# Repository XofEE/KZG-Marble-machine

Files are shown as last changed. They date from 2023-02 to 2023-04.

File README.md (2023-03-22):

# KZG-Marble-machine by Xofee

Resources and documentation related to the KZG Marble machine.

## Summary

This machine was built by [Xofee](https://twitter.com/Xofee3) in order to generate randomness to participate in the KZG ceremony.
It uses chaos theory to capture entropy. The KZG Marble Machine is a physical device that generates random numbers using the natural randomness of marble movement.

The KZG Ceremony is a public ritual aimed at providing a cryptographic foundation for Ethereum scaling efforts like proto-danksharding.

If you want more information about the KZG Ceremony, you can find it on the dedicated [GitHub Pages](https://github.com/ethereum/kzg-ceremony).
To see the machine in operation, go to this [video](https://www.youtube.com/watch?v=zKrcUxOeBF4).

## Presentation

The machine is a marble circuit. There are 13 obstacles retracing in chronological order the history of Ethereum:

- White paper
- First blocks
- Attacks
- NFT madness
- Maze of the DEFI
- The Burn
- Mining area
- The Merge
- Flow of staking
- Layers 2
- Data Blob
- Vision of the future
- Rocket lift

A complete description of each obstacle can be found in the file [Full-presentation.md](/Full-presentation.md)

## How it works

Thanks to a set of sensors, it measures the time between marbles, and it is also sensitive to its external environment.

Each time a ball completes the course, it is detected by a sensor. This causes a measurement on all the other sensors and also some light animations.
These values are aggregated and then output in one random number via USB.

Some obstacles are mechanical or motorized with servomotors. The latter also serves as a sensor to add entropy.
The course is embellished with animated LEDs to make it more entertaining.
The public present in front of the machine also participates in the entropy thanks to the microphone, light sensor and the ultrasonic sensor which measures the distance of the public from the machine.

To contribute to the KZG ceremony, the machine will directly generate a new long string of random values which will be used as a secret.
**This secret will not be recorded and will therefore be lost after participation.**

This special contribution for the KZG ceremony will take place after mid-March.

The KZG Marble Machine uses a physical process to generate randomness, which means it is not subject to the same potential biases and patterns that can be present in pseudorandom number generators. This can provide a higher level of security in applications where true randomness is essential.

The KZG Marble Machine is a physical device, which means it is more resistant to tampering than a software-based random number generator. If an attacker wants to manipulate the output of the KZG Marble Machine, they would need to physically access the device and interfere with the marbles, which can be more difficult than manipulating software.

## Random facts about the machine and its construction

- It took a total of more than 8 days of 3D printing to make all the pieces.
- A marble is detected by the sensor on average every 2.5s
- It takes about 25s for a ball to complete the full course.
- There are 42 marbles in the circuit in total, 30 of which are in the elevator.
- The course measures more than 4m in total.
- The longest obstacle is the DEFI maze which alone represents a quarter of the course.

## More info

You can find more info about the machine in the file [Full-presentation.md](/Full-presentation.md).

A [data set](/Data) of more than 16,000 values generated by the machine (CSV file available in raw, hexadecimal or binary) is available.
You can use them as random values in your projects or analyze them to check that the machine is not biased.

If you have any questions, don't hesitate to contact me on twitter at [Xofee](https://twitter.com/Xofee3).

*Randomly Xofee*

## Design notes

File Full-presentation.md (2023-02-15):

# Full presentation of The KZG Marble Machine by Xofee

## Summary 

This presentation aims to supplement the information found in the [Readme file](/README.md).

If you want more information about the KZG Ceremony, you can find it on the dedicated [GitHub Pages](https://github.com/ethereum/kzg-ceremony).

To see the machine in operation, go to this [video](https://www.youtube.com/watch?v=zKrcUxOeBF4).

## Obstacles 

We will deconstruct each obstacle of the KZG Marble Machine to understand its functioning.



The best place to start is with the title: ETHEREUM. We'll take a look at some of its major milestones.



In 2014, Vitalik published the Ethereum White Paper 📝, which marked the beginning of the project. This obstacle is powered by the logo rotating randomly 🔄, deflecting the marbles.



In 2015, 🏁 the first blocks of Ethereum were mine and worked smoothly until...



In 2016, there was a setback with the hack of The DAO and the Shanghai attack. Here we see a funnel that sucks all the marbles 🌪️.



In 2017, the NFT craze is depicted with a CryptoKitty (#634995) congesting the marble flow with its paws. 🐾



We delve into the complexities of decentralized finance with the 2020 DEFI Summer.



We find the 🔥 Burn mechanism of the EIP1559 with a switch that diverts some of the marbles. This update was implemented during the London fork in August 2021.



Next, we come to the moment of the merge symbolized by a panda 🐼. Upstream, we have the miners' pickaxes ⛏️ representing the Proof of Work era.



In September 2022, we move to proof of stake with the marbles flowing between the ETH staked 🪙.



We then reach the layer 2, which operates in parallel ⛓️ with Ethereum to improve scalability.



We arrive at a blob that absorbs data to make more room for the layer 2s. The KZG ceremony 🕯️ with the EIP 4844 will enable the deployment of this new data type.



The end of the course features a sensor measuring the final interval between two marbles to generate entropy 🎲. Then we discover a vision of a future built on Ethereum 🏙️.



Finally, we come to a rocket 🚀 (familiar to some in the community) which uses an elevator to raise the marbles to the top of the course. ⏫

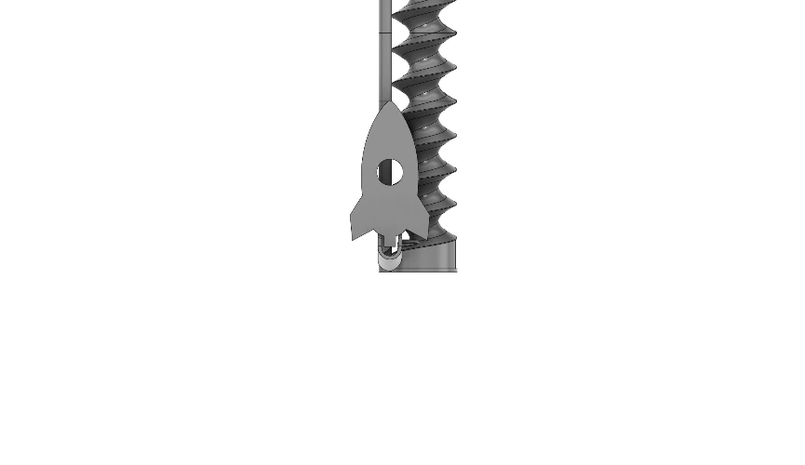
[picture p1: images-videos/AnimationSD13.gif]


## Source of entropy

The machine draws its entropy mainly from the measurement of the time between the passage of two marbles.
Indeed, during its course, each marble will follow a slightly different path which will make it encounter greatly different obstacles.
In addition, the obstacles move to add even more randomness.

The accumulation of these parameters as well as their chaotic characteristic means that the machine can be considered capable of generating pseudo random values.

Secondary entropy sources such as noise, temperature are also captured by sensors to be added as well.

### Primary

| Description  | Sensor | Range |
| - | - | - |
|Time interval between two balls| LJ12A3-4-Z/BX|~2 500 000 μs - ~12 000 000 µs|

### Secondary

| Description  | Sensor | Range |
| - | - | - |
| Sound | Adafruit MAX4466 | 0 - 1023 |
| Brightness | Iduino 1485310 | 0 - 1023 |
| Distance | Ultrasonic 28015 REV C | 0mm - 500mm |
| Electrostatic noise | Antenna length 40 cm | 0 - 1023 |
| Electrostatic noise | Antenna length 40 cm | 0 - 1023 |
| Electrostatic noise | 6 x ADC | 6 x 0 - 1023 |
| Temperature | 4 x Robotis Dynamixel MX-28AR | 4 x 0 - 255 |
| Load | 4 x Robotis Dynamixel MX-28AR | 4 x 0 - 2047 |
| Position | 4 x Robotis Dynamixel MX-28AR | 4 x 0 - 4095|

## Output

The machine aggregates all the parameters of its sensors.

It can then output this value directly* or convert it to hexadecimal or binary simply performing a modulo 16 or 2 respectively.

The order of magnitude of the sum of the outputs of all the sensors being greater than 10<sub>5</sub>, a modulo 16 can loop enough times for this value to be unpredictable.

In other words, a modulo 10 will come down to looking at the last value of a sensor outputting a 6-digit result. However, the latter is mainly influenced by the noise and not by the measured variable.

**be careful with this raw value the distribution is not homogeneous because there are more balls that finish in 2.5s than in 10s for example.*

## Control of obstacles

### Motorized obstacle

4 obstacles are controlled by servomotors:

- White paper
- NFT madness
- Mining area
- Rocket lift

These servos change speed and position randomly according to the last generated random value.
This change happens every time a marble completes the circuit or every 5s (whichever comes first).

### Mechanical obstacle

The burn is a special obstacle since it is a switch that separates half of the marbles. The burnt balls are sent on a faster path towards the end of the course.

## List of materials:

If you want to build this machine yourself, you will find below a non-exhaustive list of the necessary materials:

- White and gray PLA 3D printed parts
- Back board 45x66cm
- 4 x Robotis Dynamixel MX-28AR
- 1 x OpenCM 9.04 board
- 1 x OpenCM EXP 485 power board
- 1 x 12v 3A powersupply
- 1 x LJ12A3-4-Z/BX inductive proximity sensor
- 1 x Mic Adafruit MAX4466
- 1 x Brightness sensor Iduino 1485310
- 1 x Ultrasonic sensor 28015 REV C
- 2 x Strip of Neopixels LED

[Files](/3D%20files) and [code](/program) are available in opensource on this github.

If you have any questions, don't hesitate to contact me on twitter at [Xofee](https://twitter.com/Xofee3).

*Randomly Xofee*

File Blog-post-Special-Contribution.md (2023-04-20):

# The KZG Marble Machine: My special Contribution to Ethereum’s KZG Ceremony
## Subtitle:

*A closer look at the elaborate contraption that uses marbles to generate random numbers for the Ethereum KZG Ceremony.*

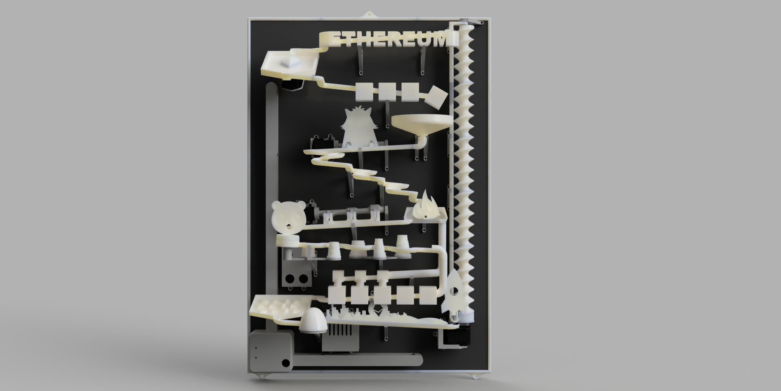
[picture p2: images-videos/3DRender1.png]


*The KZG Marble Machine*

## Introduction:
Cryptography is a fascinating world that thrives on creativity and innovation. In this extended blog post, I’m excited to share details about my one-of-a-kind contribution to the Ethereum KZG Ceremony using the KZG Marble Machine, an elaborate contraption designed to provide a unique source of randomness for the proceedings.

## Background:
The KZG Ceremony is a decentralized alternative to a trusted setup, which outputs public parameters for a polynomial commitment scheme. The ceremony relies on contributions from multiple participants, guaranteeing integrity as long as at least one participant acts honestly in generating their contribution and destroying the secret.

To reinforce the ceremony’s security, the Ethereum Foundation called for special contributions, including unique sources of randomness.

That’s where my KZG Marble Machine comes into play!

## The KZG Marble Machine:
The KZG Marble Machine is an intricate, custom-built contraption that uses marbles to generate random numbers. The machine features 13 obstacles, each symbolizing a milestone in Ethereum’s history. As marbles move through the machine, they interact with these obstacles and various components, creating unpredictable patterns. The result is a truly unique and random sequence of numbers that I used for my special contribution to the KZG Ceremony.

To see the machine in operation, go to this [video](https://www.youtube.com/watch?v=zKrcUxOeBF4).

## Entropy Sources:
Multiple entropy sources influence the machine’s sensors, ensuring an even higher degree of randomness. These sources include the initial position of the marbles, friction between components, air resistance, and vibrations in the machine’s structure.

Additionally, the KZG Marble Machine is equipped with ultrasonic sensors, microphones, and antennas, which incorporate environmental factors as supplementary sources of entropy. This feature allows the machine to generate even more unpredictable random numbers.



*Breakdown of the full KZG Marble Machine*

## The Process:
The KZG Marble Machine sent 420 random hexadecimal values (i.e. 1680 values in binary) through the serial port of an air-gapped PC via a USB cable. This air-gapped PC performed the necessary computations to generate my contribution to the KZG Ceremony. Once the calculations were completed, I transferred the resulting file to a USB stick and then to a separate computer, which sent my contribution to the sequencer.

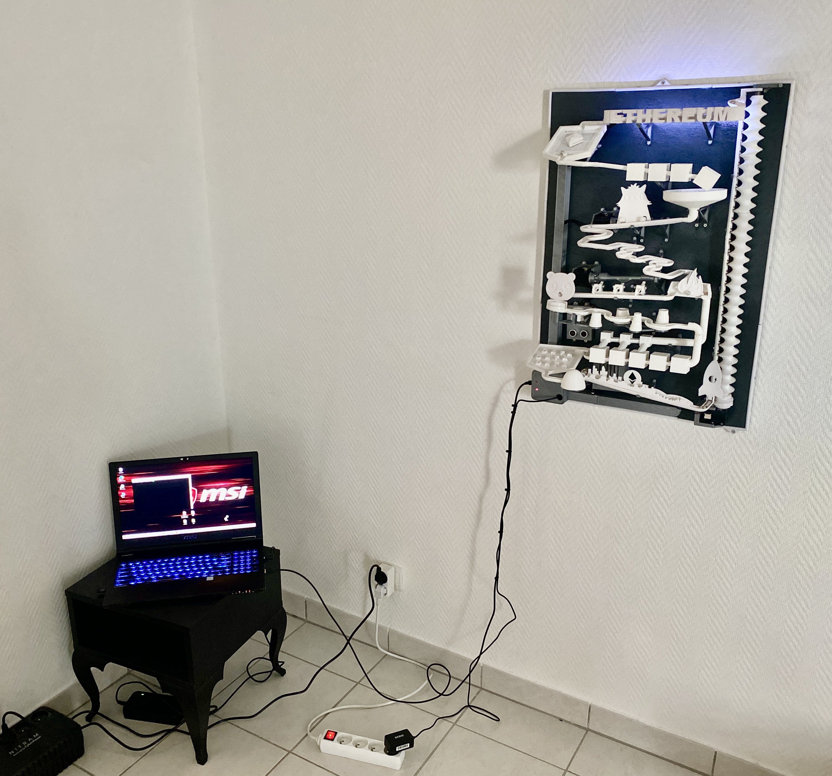
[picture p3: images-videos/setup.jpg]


*Setup beforethe contribution*

Importantly, the 420 random hexadecimal values were never recorded nor fully seen by me. After transferring the file, both the air-gapped PC and the USB stick were completely formatted to ensure no trace of the random values or my contribution remained.

## Documentation:
For more information on the KZG Marble Machine and the process, please visit the [GitHub Pages](https://github.com/ethereum/kzg-ceremony).
The machine is fully opensourced. All 3D files, programs and component list are available on Github.

## Proof of Contribution:
As proof of my contribution, here is a screenshot of the sequencer showing my Ethereum address ( xofee.eth : 0xFF141bFc450c57Ad84eBaFbD09ffa94A268a7aaE ) and contribution number (#83329) .

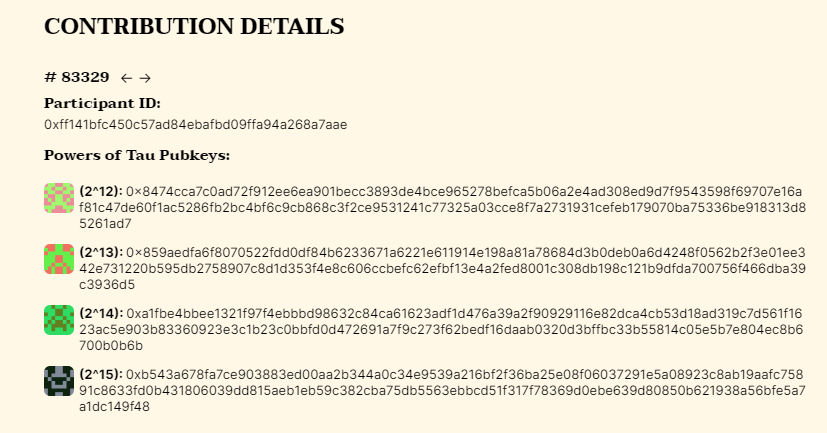
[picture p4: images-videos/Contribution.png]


*#83329 Contribution details*

[My twitter post](https://twitter.com/Xofee3/status/1644033756066467840?s=20)

## Conclusion:
The KZG Marble Machine is a unique and innovative contribution to the KZG Ceremony. Its ability to generate random numbers using marbles and various sources of entropy makes it a valuable addition to the security of the ceremony. The machine’s intricate design and the attention to detail that went into its creation are a testament to the creativity and innovation that thrives in the world of cryptography. The fact that the machine is open-sourced further enhances its value as a contribution to the Ethereum community, and its documentation provides valuable insights into the process. Finally, we should not forget to thank all the people involved in making this possible, from the organizers of the KZG Ceremony to those who provided support and inspiration along the way.

Overall, the KZG Marble Machine is a fascinating example of how creativity and innovation can contribute to the security of decentralized systems.

*Randomly Xofee*

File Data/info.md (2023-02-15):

# Data set info

This folder contains a data set with 16500 random values generated by the machine.
These measurements was made in more than 12 hours of operation of the machine.
You can use them as random values in your owns projects or analyze them to check that the machine is not biased.
The files are in CSV format.

The raw.csv file contains the aggregated values of all sensors each time a marble passes in front of the sensor.     
**be careful with this raw value the distribution is not homogeneous because there are more balls that finish in 2.5s than in 10s for example.*

The hex.csv and bin.csv files give the same values in Hexadecimal and in binary. 
**These are the pseudo-random data generated by the machine.**
They are obtained by respectively performing a modulo 16 and 2 on the raw data.

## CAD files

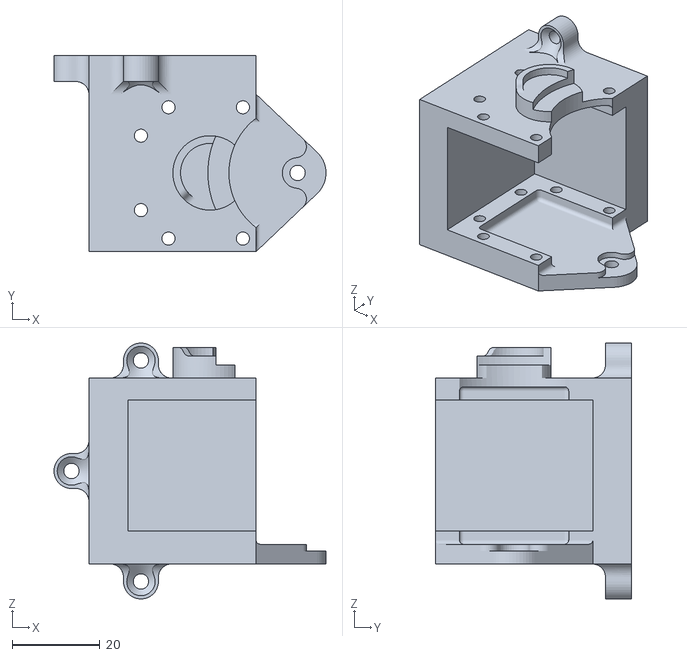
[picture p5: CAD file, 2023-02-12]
3D files/STL/00-Assembly v20_00-Assembly v20_13-Servo v1_1_Corps1.stl
62.2 x 44.9 x 58.5

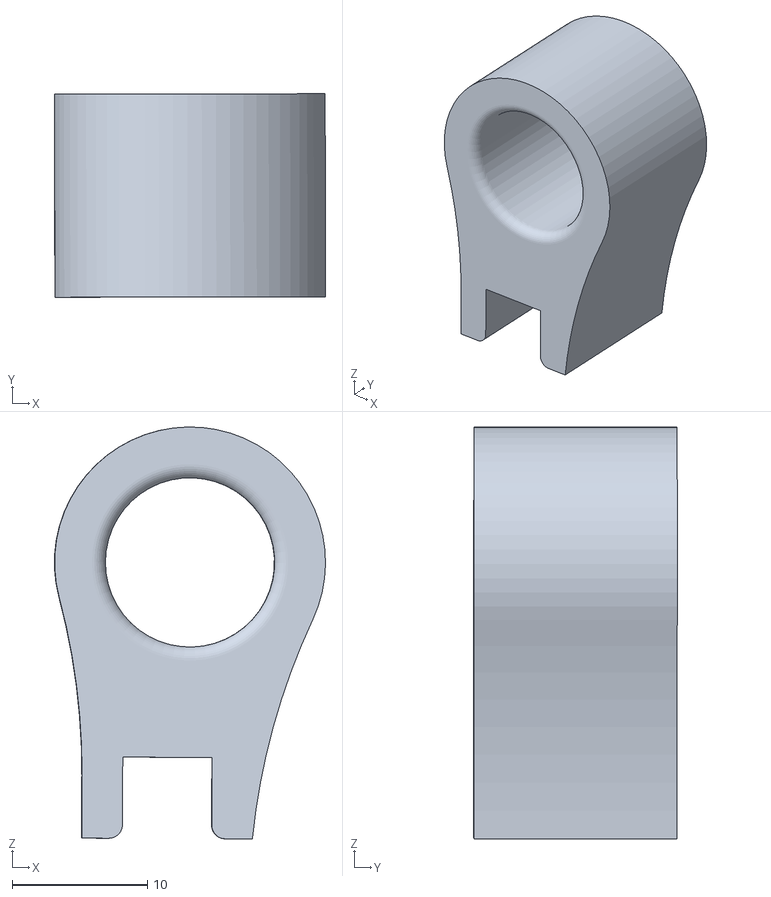
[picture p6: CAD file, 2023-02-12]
3D files/STL/00-Assembly v20_00-Assembly v20_12-support Sensor v1_1_Corps1.stl
20.0 x 15.0 x 30.4

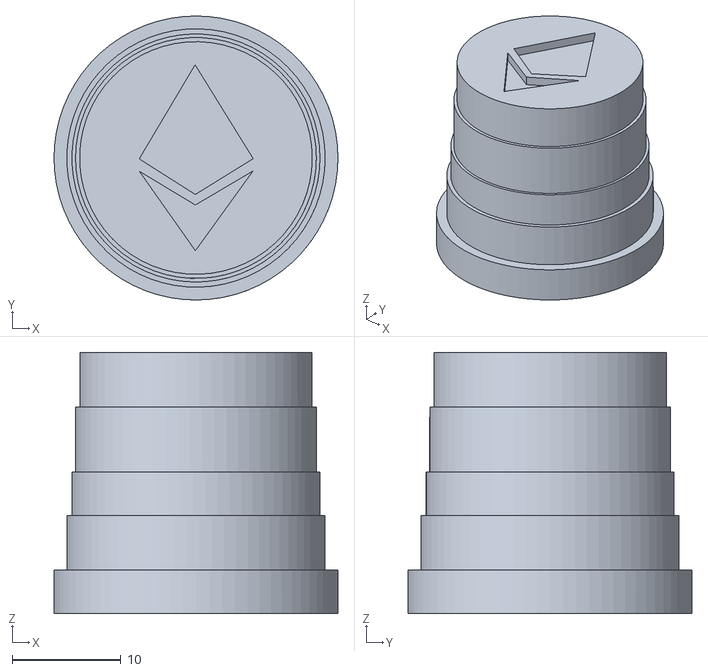
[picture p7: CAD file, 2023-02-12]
3D files/STL/00-Assembly v20_00-Assembly v20_09-Staking v6_1_Corps5.stl
26.1 x 26.1 x 24.0

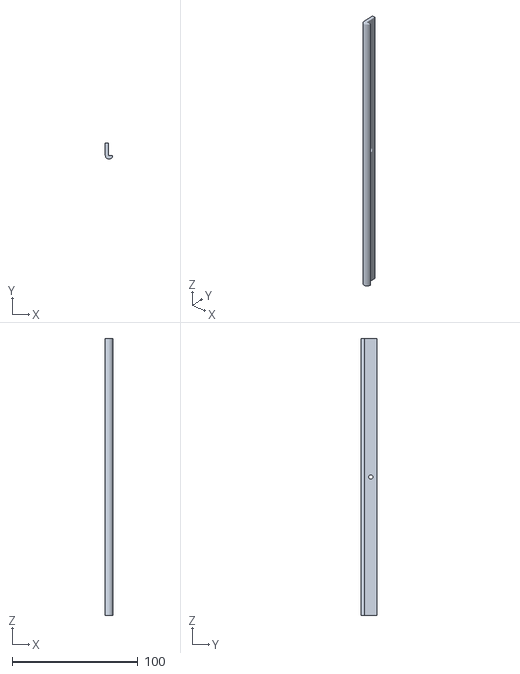
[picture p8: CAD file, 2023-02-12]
3D files/STL/00-Assembly v20_00-Assembly v20_Edge (CL).stl
6.00 x 13.0 x 220.0

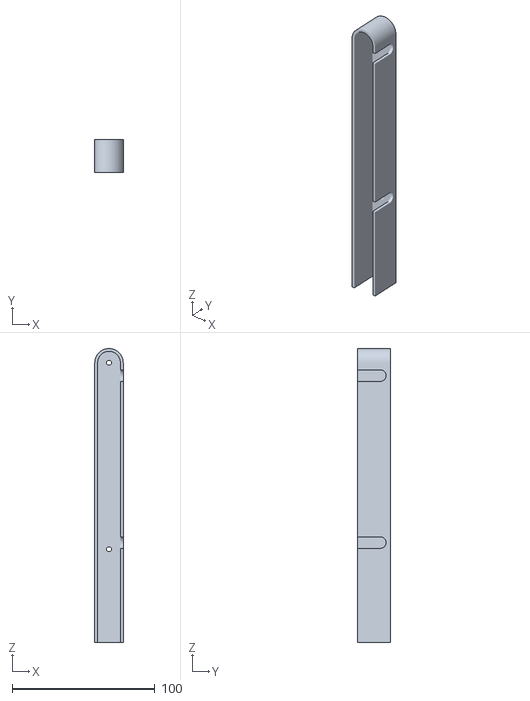
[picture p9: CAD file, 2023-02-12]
3D files/STL/00-Assembly v20_00-Assembly v20_Cable v10_1_A.stl
20.0 x 23.0 x 206.0

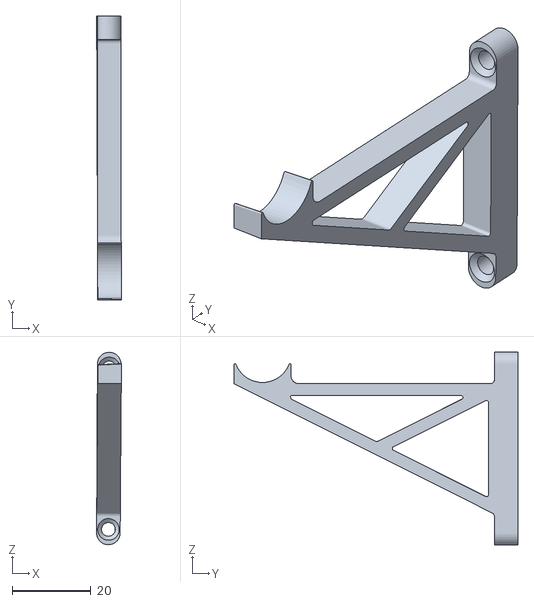
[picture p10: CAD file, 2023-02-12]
3D files/STL/00-Assembly v20_00-Assembly v20_10-support6mm v1_1_Corps1.stl
6.32 x 72.3 x 49.0

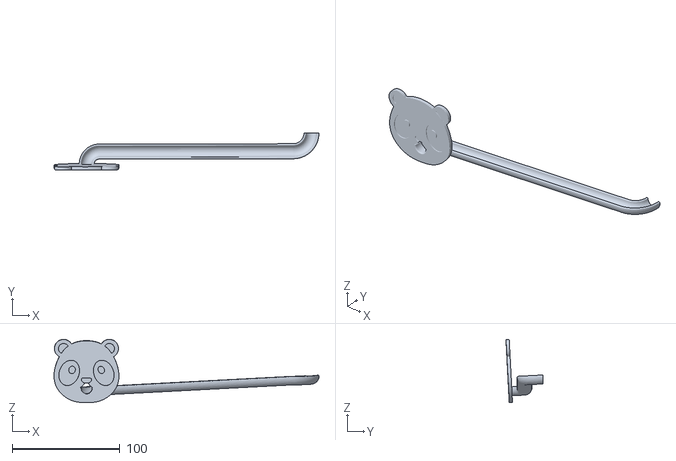
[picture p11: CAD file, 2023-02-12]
3D files/STL/00-Assembly v20_00-Assembly v20_08-Miner v10_1_Corps1.stl
246.1 x 34.5 x 58.9

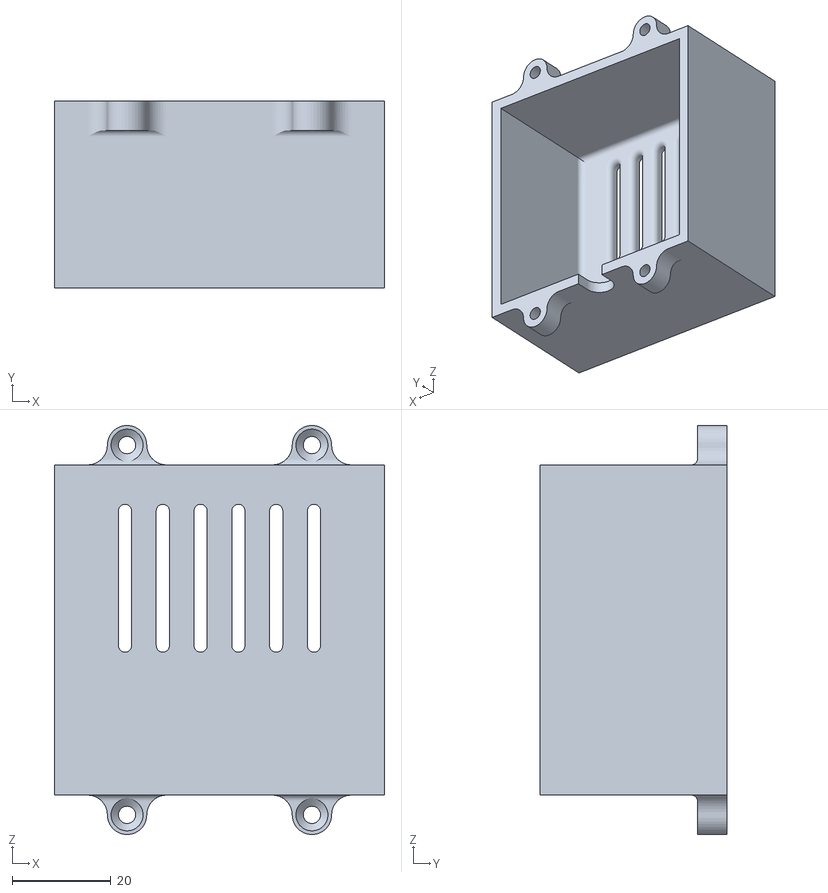
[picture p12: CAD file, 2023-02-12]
3D files/STL/00-Assembly v20_00-Assembly v20_LedBox v1_1_Corps1.stl
67.0 x 38.0 x 83.0

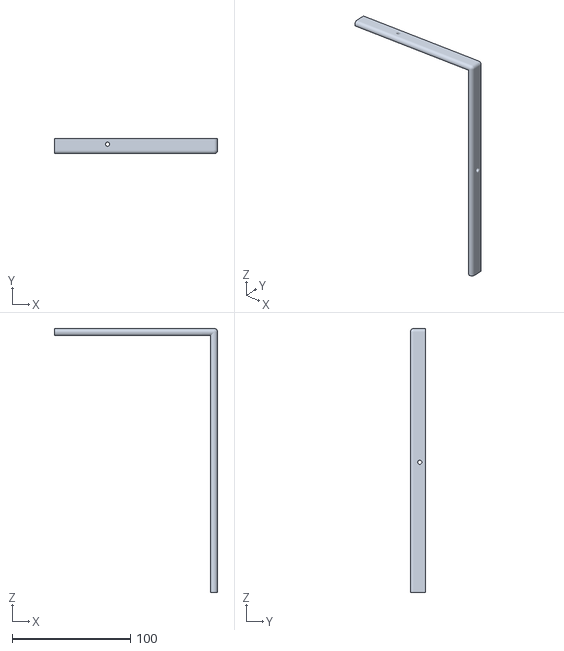
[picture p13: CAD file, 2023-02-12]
3D files/STL/00-Assembly v20_00-Assembly v20_Edge (UR).stl
138.0 x 13.0 x 223.0

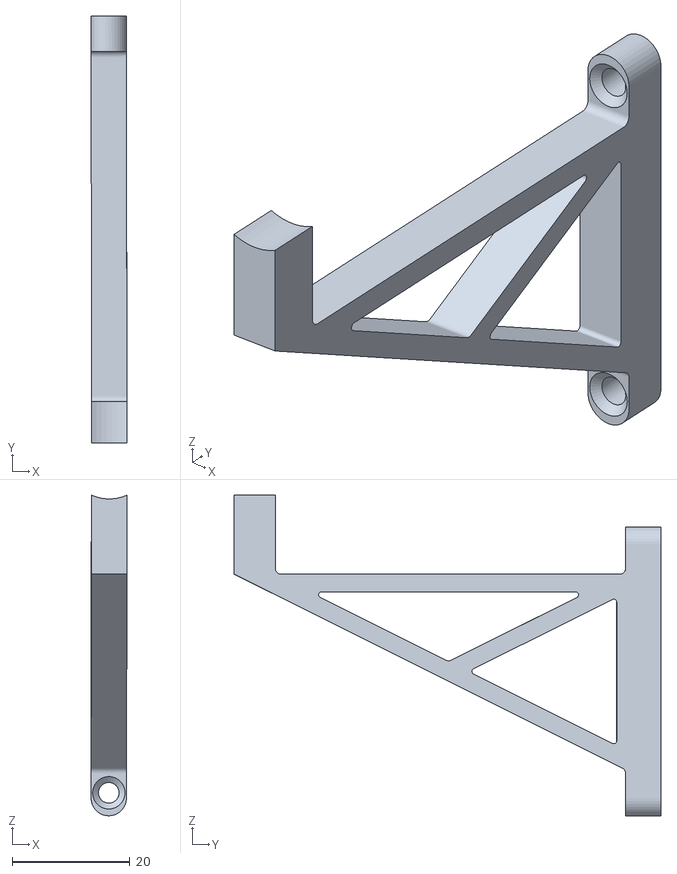
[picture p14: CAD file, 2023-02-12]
3D files/STL/00-Assembly v20_00-Assembly v20_07-support6mm v1_1_Corps1.stl
6.12 x 72.4 x 54.4

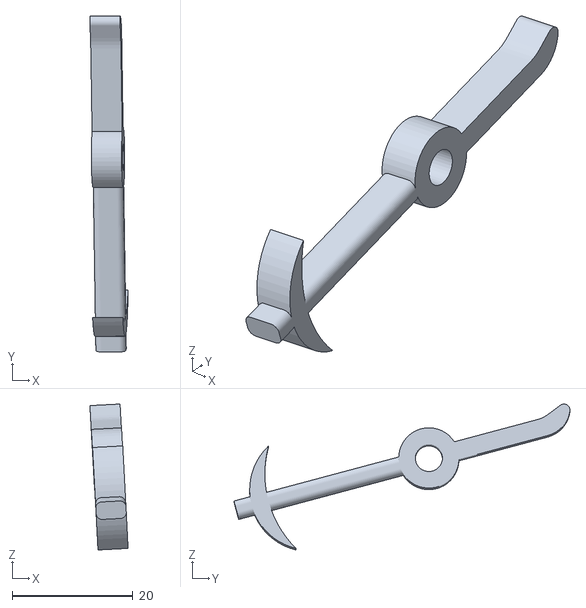
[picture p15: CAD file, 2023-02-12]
3D files/STL/00-Assembly v20_00-Assembly v20_08-Miner v10_1_Pioche(Symétrie miroir) (1)_1_Corps1.stl
6.32 x 55.6 x 24.2

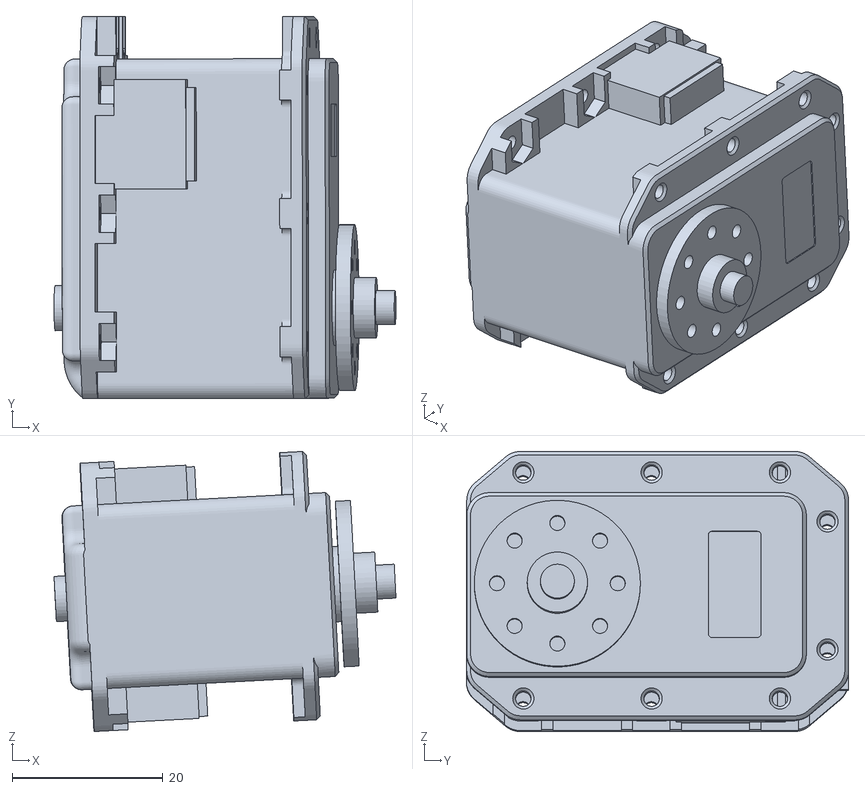
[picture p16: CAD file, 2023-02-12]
3D files/STL/00-Assembly v20_00-Assembly v20_08-Servo v1_1_MX-28AT_AR v2_1_Corps1.stl
45.3 x 50.6 x 37.1

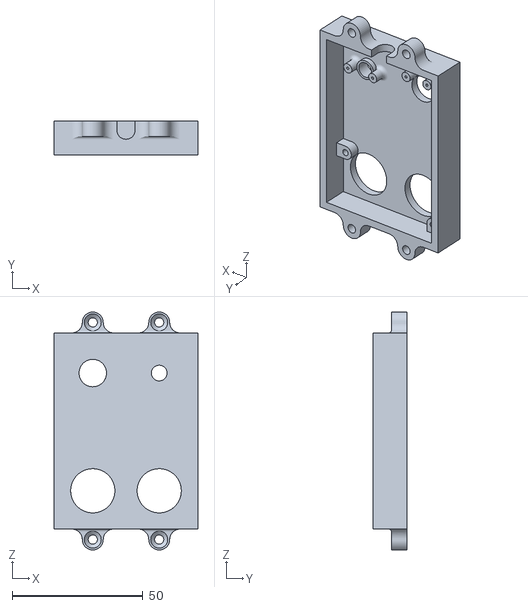
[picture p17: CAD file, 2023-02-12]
3D files/STL/00-Assembly v20_00-Assembly v20_SensorsBox v3_1_Corps2.stl
55.0 x 13.0 x 91.0

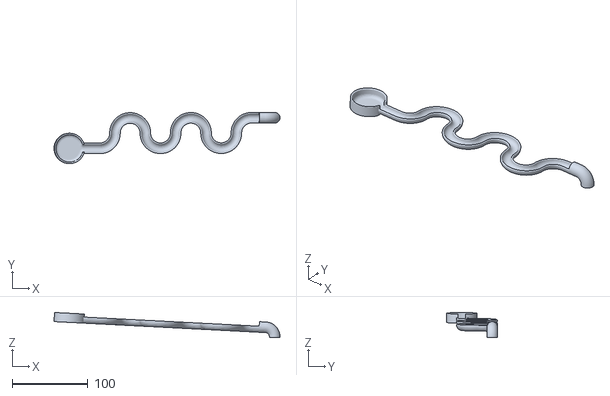
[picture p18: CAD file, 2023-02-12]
3D files/STL/00-Assembly v20_00-Assembly v20_09-Staking v6_1_Corps1.stl
297.4 x 67.4 x 33.0

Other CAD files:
3D files/STL/00-Assembly v20_00-Assembly v20_Cable v10_1_Corps20.stl
3D files/STL/00-Assembly v20_00-Assembly v20_Edge (BR).stl
3D files/STL/00-Assembly v20_00-Assembly v20_09-support6mm v1_1_Corps1.stl
3D files/STL/00-Assembly v20_00-Assembly v20_09-Staking v6_1_Corps2.stl
3D files/STL/00-Assembly v20_00-Assembly v20_01-Ethereum v7_1_Corps15.stl
3D files/STL/00-Assembly v20_00-Assembly v20_01-support6mm v2_1_Corps1.stl
3D files/STL/00-Assembly v20_00-Assembly v20_01-support6mm v2_2_Corps1.stl
3D files/STL/00-Assembly v20_00-Assembly v20_02-Whitepaper v7_1_02-Servo v6_1_Corps1.stl
3D files/STL/00-Assembly v20_00-Assembly v20_02-Whitepaper v7_1_Corps1.stl
3D files/STL/00-Assembly v20_00-Assembly v20_02-Whitepaper v7_1_Corps13.stl
3D files/STL/00-Assembly v20_00-Assembly v20_02-Whitepaper v7_1_Corps4.stl
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

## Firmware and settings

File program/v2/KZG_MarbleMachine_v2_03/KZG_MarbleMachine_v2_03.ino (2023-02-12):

#include <Adafruit_NeoPixel.h> //library for LED

/* Display Output mode */
#define HEXA 0
#define BINA 0
#define TIME 0
#define VALU 1

/* Parameters */
#define TCHANGE 5000 //max time between change of speed for Dynamixel  
#define BRI 50 //LED Brightness
#define TCUT 500 //min time between 2 values to skip rebounce or double marbles
#define TLED 300//time for led animation


/* ID Servo defines Robotis Dynamixel MX-28AR */
#define ELE 1 //Elevator
#define MIN 2 //Miner
#define CAT 3 //Crypto Kitty
#define EWP 4 //Ethereum White Paper

/* Pin defines */
#define SEN 18 //Inductive Proximity Sensorb LJ12A3-4-Z/BX

#define SOU 3 //digital pin for neopixe
#define LUM 1 //digital pin for neopixel
#define ULT 19 //digital pin for neopixel
#define ANT1 8 //digital pin for neopixe
#define ANT2 9 //digital pin for neopixel

#define LEDH 21 //digital pin for neopixe
#define LEDB 20 //digital pin for neopixel

/* Dynamixel Control table defines */
#define CW_Angle_Limit 6
#define CCW_Angle_Limit 8
#define GOAL_SPEED 32
#define PRESENT_POSITION 36
#define PRESENT_LOAD 40
#define PRESENT_TEMPERATURE 43
#define MOVING 46

 /* Serial device defines for dxl bus */
Dynamixel Dxl(3);

Adafruit_NeoPixel pxB = Adafruit_NeoPixel(32, LEDB, NEO_GRB + NEO_KHZ800);
Adafruit_NeoPixel pxH = Adafruit_NeoPixel(32, LEDH, NEO_GRB + NEO_KHZ800);


unsigned long t_marble =0; //timer between marble
unsigned long val =0; //random value output
unsigned long t_change =0; //random value output
unsigned long t_led =0; //random value output
int pos[5];
int load[5];
int temp[5];

byte lineH=0;
byte lineB[200];

float xH=0;

/*Setup*/
void setup() {
  //Pin configuration
  pinMode(SEN, INPUT_PULLDOWN);//sensor pin
  pinMode(ULT, INPUT_PULLDOWN);//ultrason pin
  
  for(int i =0;i<10;i++){//config analog pin to add as a source of noise 
    pinMode(i, INPUT_ANALOG);
  }

  // Dynamixel 2.0 Protocol -> 0: 9600, 1: 57600, 2: 115200, 3: 1Mbps 
  Dxl.begin(1);
  
  
  //Wheelmode
  Dxl.writeWord(ELE, CW_Angle_Limit, 0);
  Dxl.writeWord(ELE, CCW_Angle_Limit, 0); 
  
  Dxl.writeWord(MIN, CW_Angle_Limit, 0);  
  Dxl.writeWord(MIN, CCW_Angle_Limit, 0);
  
  Dxl.writeWord(CAT, CW_Angle_Limit, 0); 
  Dxl.writeWord(CAT, CCW_Angle_Limit, 0); 
  
  //JointMode
  Dxl.writeWord(ELE, CW_Angle_Limit, 0);
  Dxl.writeWord(ELE, CCW_Angle_Limit, 0); 
 
  
  //Start wheel mode servo
  Dxl.writeWord(ELE, GOAL_SPEED, 300 | 0x400); //reverse
  Dxl.writeWord(MIN, GOAL_SPEED, 100);
  Dxl.writeWord(CAT, GOAL_SPEED, 100);
  
  //Start servo
  Dxl.setPosition(EWP,2048,100);
  
  //Start time
  t_marble=micros(); //save time for restart counter
  t_change=micros(); //save time for restart counter
  
  read_dynamixel();//update value from dynamixels sensors and analogpin
  
  for(int i =0;i<150;i++){//init array with zeros 
    lineB[i]=0;
  }

  //Start led
  pxH.begin();
  pxH.setBrightness(BRI);
  
  pxB.begin();
  pxB.setBrightness(BRI);
  
  update_led();
  
}

/*Loop*/
void loop() {
  
  if((digitalRead(SEN)==LOW) && (abs(micros()-t_marble) > TCUT*1000)){// if there is a new marble more than TCUT ms after the last
  
    digitalWrite(BOARD_LED_PIN, LOW);//LED on board ON
    update_value();//update value with sensors from all dynamixel and analog pin
    ultrasound(); //update value with ultrasound sensor
    
    
    if (HEXA) SerialUSB.print(val%16,HEX);
    else if (BINA) SerialUSB.print(val%2);
    else if (TIME) SerialUSB.println(micros()-t_marble);
    else if (VALU) SerialUSB.println(val);
    
    t_marble=micros(); //save time for restart counter
    t_change= t_change-TCHANGE*1000;//force update servo
    
    sinB();//add pulse lEDB 
    
    while (digitalRead(SEN)==LOW) delay(50);//wait for stuck marble or no Power
  }
  else {
    digitalWrite(BOARD_LED_PIN, HIGH);//LED on board OFF
  }
  
  //change speed of servo if marble detected or too long
  if (abs(micros()-t_change) > TCHANGE*1000){
    t_change=micros(); //save time for restart counter
    
    update_value();//update value with sensors from all dynamixel
    
    //change speed of dynamixel
    Dxl.writeWord(ELE, GOAL_SPEED, 200+val%101 | 0x400); //101 arbitrary value
    Dxl.writeWord(MIN, GOAL_SPEED, 100+val%43); //43 arbitrary value
    Dxl.writeWord(CAT, GOAL_SPEED, 100+val%193);//193 arbitrary value
    
    Dxl.setPosition(EWP,1365+val%1021,50+val%101);//101 arbitrary value
    }
    
    if (micros()%TLED*1000==0){//sinus on LEDH
    xH=xH+0.0031415;
    if (xH>3.1415) xH=0.0;
    
    lineH=20+sin(xH)*50;
    }
    
    
    if(micros()%900==0){//update LED
      move_line();
      update_led();
    }  
    

}

/*Fonctions*/

int read_dynamixel(void){//read sensors from all dynamixel
  for (int i=0;i<4;i++){
    pos[i+1] =Dxl.readWord(i+1, PRESENT_POSITION);
    load[i+1]=Dxl.readWord(i+1, PRESENT_LOAD);
    temp[i+1]=Dxl.readByte(i+1, PRESENT_TEMPERATURE);
  } 
  
  return 0;
}

int update_value(void){//update value with sensors from all dynamixel
  val = micros()-t_marble; //calculation of the time interval between two marbles
    
    read_dynamixel();//read value from dynamixels sensors    
    for (int i=0;i<4;i++){//adding values from Dynamixel Servos sensors
    val = val + pos[i+1];
    val = val + load[i+1];
    val = val + temp[i+1];
  } 
  
  for(int i =0;i<10;i++){
    val = val + analogRead(i);//add value from floating analog pin, antenna, light sensor and mic
  }
  
  return 0;
}

int ultrasound(void){
    // establish variables for duration of the ping, and the distance result
  // in centimeters:
  float duration, mm;

  // The PING))) is triggered by a HIGH pulse of 2 or more microseconds.
  // Give a short LOW pulse beforehand to ensure a clean HIGH pulse:
  pinMode(ULT, OUTPUT);
  digitalWrite(ULT, LOW);
  delayMicroseconds(2);
  digitalWrite(ULT, HIGH);
  delayMicroseconds(5);
  digitalWrite(ULT, LOW);

  // The same pin is used to read the signal from the PING))): a HIGH pulse
  // whose duration is the time (in microseconds) from the sending of the ping
  // to the reception of its echo off of an object.
  pinMode(ULT, INPUT);
  duration = rdpulseIn(ULT, HIGH,50);

  // convert the time into a distance in mm
  mm = duration/58.2;
  
  val = val+mm;//
  
  return 0;
}

unsigned long rdpulseIn(int pin, int value, int timeout) { // the following comments assume that we're passing HIGH as value. timeout is in milliseconds

    unsigned long now = micros();
    while(digitalRead(pin) == value) { // wait if pin is already HIGH when the function is called, but timeout if it never goes LOW
        if (micros() - now > (timeout*1000)) {
            return 0;
        }
    }

    now = micros(); // could delete this line if you want only one timeout period from the start until the actual pulse width timing starts
    while (digitalRead(pin) != value) { // pin is LOW, wait for it to go HIGH befor we start timing, but timeout if it never goes HIGH within the timeout period
        if (micros() - now > (timeout*1000)) { 
            return 0;
        }
    }

    now = micros();
    while (digitalRead(pin) == value) { // start timing the HIGH pulse width, but time out if over timeout milliseconds
        if (micros() - now > (timeout*1000)) {
            return 0;
        }
    }
    return micros() - now;
}

int move_line(void){//move array right for B
  for(int i =0;i<149;i++){
    lineB[149-i]=lineB[148-i];
  }
 return 0; 
}

int sinB(void){//add sinus to the start of LEDB array
  float x =0.0;
  for(int i =0;i<20;i++){
    lineB[i]=sin(x)*255;
    x=x+0.157;
  }
 return 0; 
}

int update_led(void){//update LED
  for(int i =0;i<13;i++){
    pxH.setPixelColor(i,lineH,lineH,lineH); 
  }
  pxH.show();
  for(int i =0;i<11;i++){
    pxB.setPixelColor(i,lineB[i*10+59],lineB[i*10+59],lineB[i*10+59]);
  }
  pxB.show();
 return 0; 
}
